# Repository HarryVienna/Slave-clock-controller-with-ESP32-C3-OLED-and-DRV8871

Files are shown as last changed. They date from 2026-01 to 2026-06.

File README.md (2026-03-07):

# ESP32-C3 Slave Clock Controller

A compact, affordable, and robust controller for analog slave clocks and flip clocks (e.g., Bodet), based on the **ESP32-C3** microcontroller and the **DRV8871** H-Bridge driver.




## 📖 Overview

This project replaces bulky and expensive master clocks with a tiny PCB powered by a single Li-Ion battery. It synchronizes time via NTP and offers a web-based configuration interface.

**Key Features:**
* **Universal Support:** Works with standard 12V/24V slave clocks and Bodet flip clocks (including date motor support).
* **Compact Design:** Built around the tiny ESP32-C3 (RISC-V) and DRV8871.
* **Battery Backup:** Integrated TP4056 charging logic with deep discharge protection; keeps time during power outages.
* **WiFi Provisioning:** Easy setup via a Captive Portal (no hardcoded credentials).
* **OLED Display:** Shows status, IP, and current time (0.42" OLED).
* **Automatic Catch-up:** Automatically fast-forwards the clock if it lags behind system time.

🔗 **Read the full story and build log:** [Harald Kreuzer's Blog](https://www.haraldkreuzer.net/en/news/slave-clock-controller-esp32-c3-and-drv8871-compact-and-affordable)

## 🛠 Hardware Components

The system is built using four main modules:

1.  **Microcontroller:** ESP32-C3 (RISC-V, Single Core) with 0.42" OLED.
2.  **Motor Driver:** DRV8871 H-Bridge (3.6A peak, 6.5V-45V).
3.  **Power Management:** TP4056 USB-C Li-Ion charger.
4.  **Voltage Booster:** SX1308 Step-Up Converter (boosts battery voltage to 12V/24V).

> **Note for Bodet Clocks:** The PCB includes slots for specific diodes to drop the voltage for the 3V date motor found in Bodet flip clocks.

## 🔌 PCB

PCB Image

## 💻 Software Architecture

The firmware is written in C++ using the **ESP-IDF Framework**. It is modular and uses FreeRTOS tasks.

```mermaid
graph TD
    Main[main.cpp] --> SlaveClock
    Main --> Display
    Main --> Button
    Main --> WifiProv[WifiProvisioner]
    
    SlaveClock -->|GPIO| DRV8871[Motor Driver]
    Display -->|I2C| OLED[SSD1306]
    Button -->|GPIO| UserInput
    WifiProv -->|WiFi| SNTP[NTP Server]
```

### Modules
* **SlaveClock:** Manages the Lavet stepper motor logic (polarity inversion) and tracks the hands' position.
* **Display:** Handles the UI via `u8g2` library, including a screensaver to prevent burn-in.
* **Button:** Debounces input and detects Short Press, Long Press, and Double Click.
* **WifiProvisioner:** Handles the Captive Portal and SNTP synchronization.

## 🤝 Acknowledgments

* **PCBWay** for sponsoring the PCB manufacturing for this project.
* **u8g2** library for the display graphics.

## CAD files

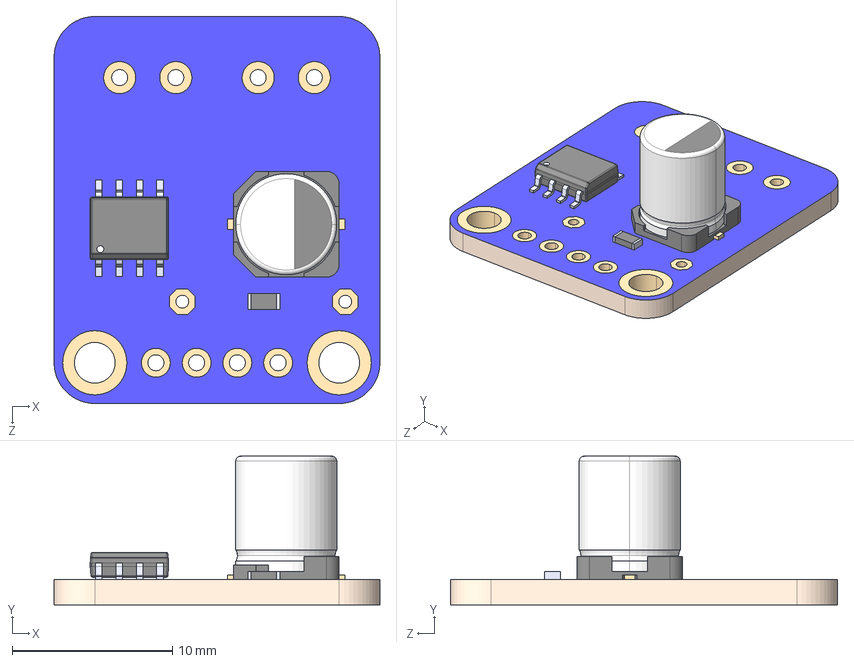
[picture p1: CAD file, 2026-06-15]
KiCAD/DRV8871/DRV8871.step
20.3 x 9.27 x 24.1 mm
Panasonic_D_22uF_63V_Panasonic_D_22uF_63V
DRV8871_DRV8871

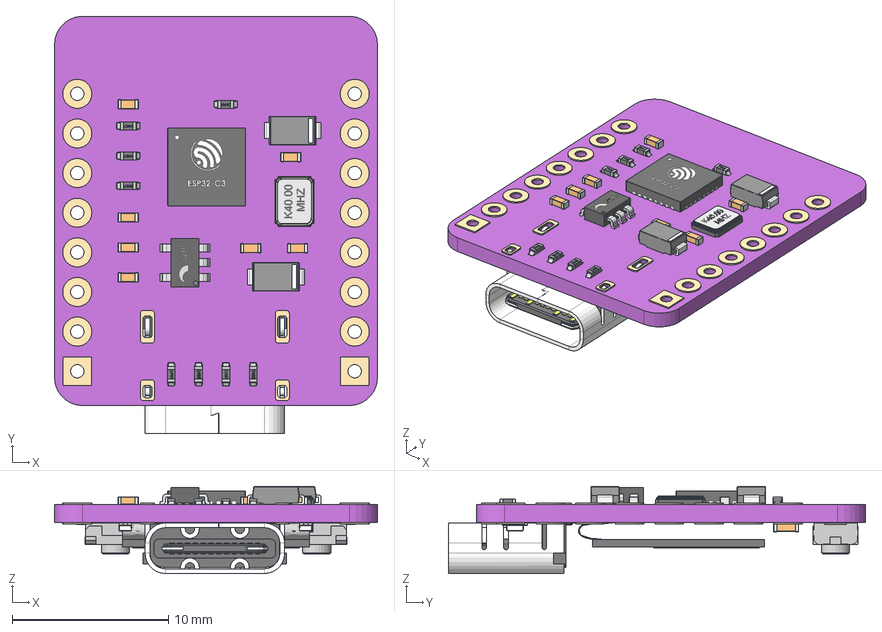
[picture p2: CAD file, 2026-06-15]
KiCAD/ESP32-C3_OLED/ESP32-C3_OLED4.2.step
20.7 x 26.7 x 5.58 mm
ESP32-C3
40.00 MHz Oscillator v1
Light x 2
Anode Bottom x 2
Cathode Bottom x 2
Anode x 2
Cathode x 2
Base x 2
3x4x2 tact button v1 v1 x 2
ME6211-SOT23 v1
USB_type_C_smd_12p v1
Anode Bottom (1)
Cathode Bottom (1)
Anode (1)
Cathode (1)
Base (1)
Text
Board
OLED 4.2
Pads
Resistor 0402 v1 x 8
Resistor 0402 v1 (1)
Refdes x 2
Cathode (2) x 2
Anode (2) x 2

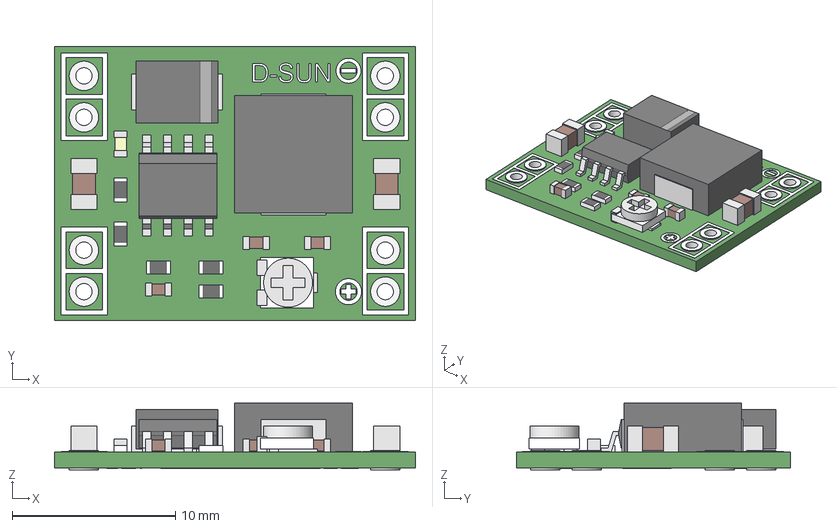
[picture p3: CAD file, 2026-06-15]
KiCAD/MP1584EN/MP1584EN_Module.step
22.1 x 16.8 x 4.10 mm
main001
silk-TOP
pins
silk-bot
comp-top

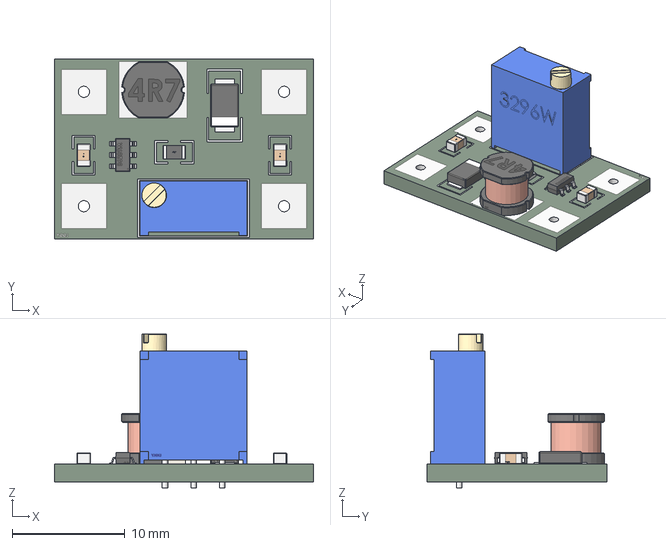
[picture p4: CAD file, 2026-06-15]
KiCAD/SX1308/YAAJ_DCDC_StepUp_SX1308_cp.step
23.0 x 16.0 x 13.7 mm

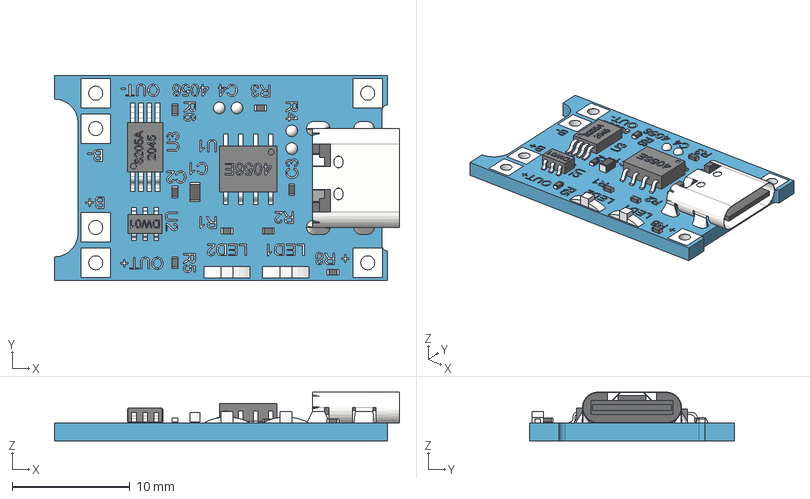
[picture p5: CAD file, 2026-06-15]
KiCAD/TP4056/TP4056_Charging_Module_Type_C.step
29.3 x 17.4 x 4.14 mm
board
USB_Type_C_Connector
8205A_2045
DW01-P
small1005_smd_resistor x 2
small1005_smd_resistor (1)
small1005_smd_capacitor
smd_capacitor
SOP-8_4056E
solder_dot_round
solder_dot_round (1)
solder_dot_round (2)
solder_dot_round (3)
small1005_smd_capacitor (1)
LED2
LED2 (1)
small1005_smd_resistor (2)
small1005_smd_resistor (4) x 2
soldering

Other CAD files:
KiCAD/DRV8871/DRV8871.stp

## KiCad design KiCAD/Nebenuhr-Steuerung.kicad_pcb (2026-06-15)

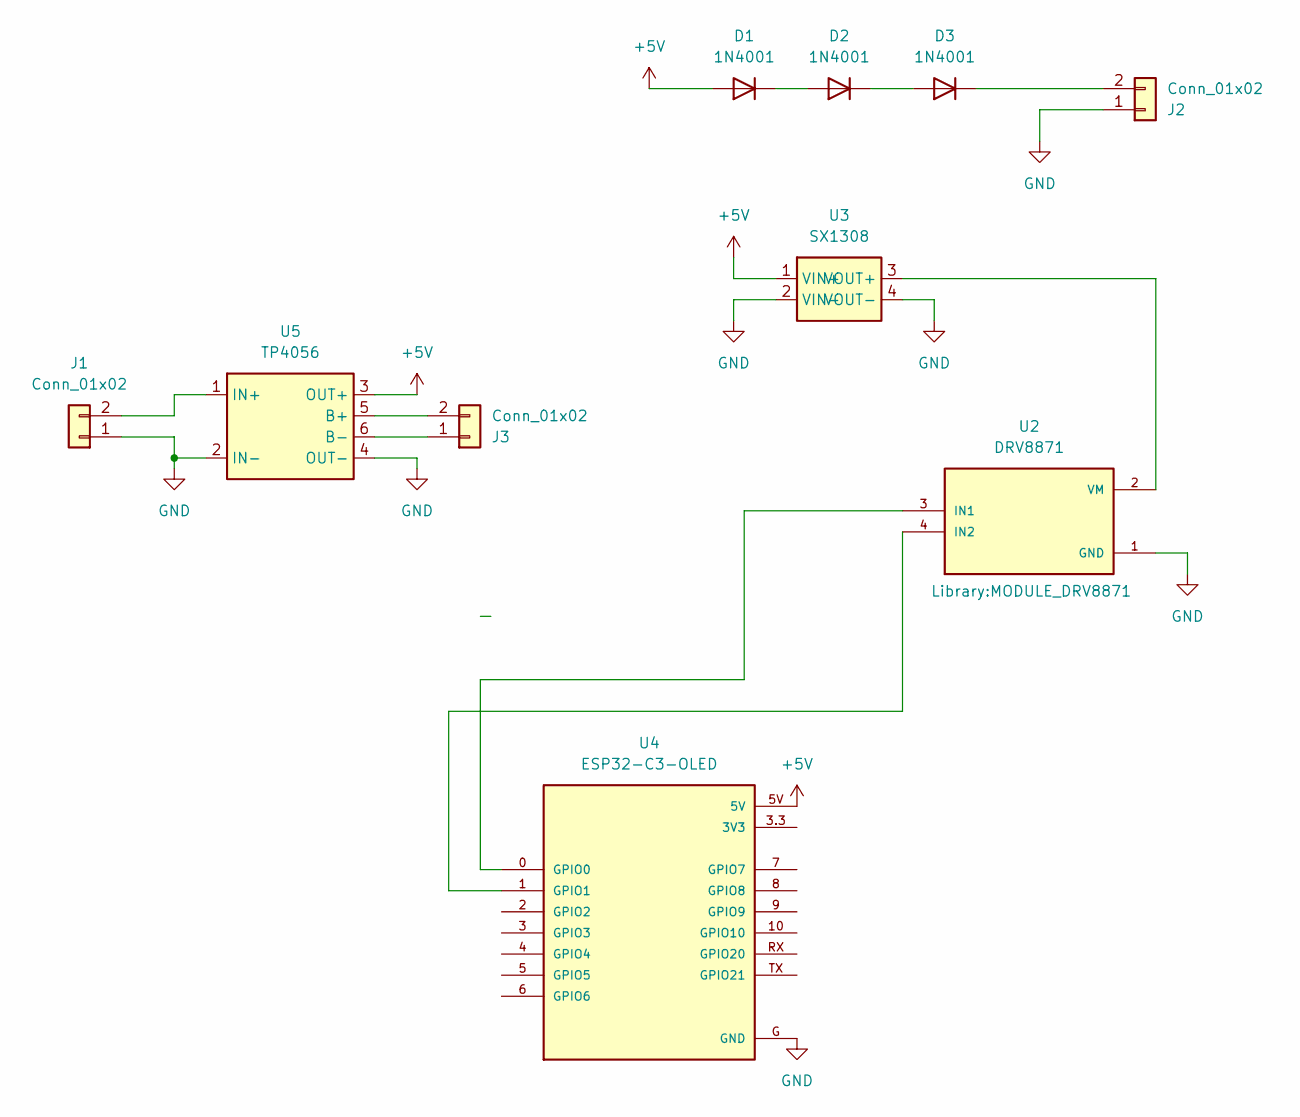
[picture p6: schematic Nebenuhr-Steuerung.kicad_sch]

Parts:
D1, D2, D3: 1N4001; D_DO-41_SOD81_P10.16mm_Horizontal
J1, J2, J3: Conn_01x02; TerminalBlock_Phoenix_PT-1,5-2-5.0-H_1x02_P5.00mm_Horizontal
U2: DRV8871; MODULE_DRV8871; PARTREV 2021-11-15
U3: SX1308; SX1308_Boost_Module
U4: ESP32-C3-OLED; MODULE_ESP32-C3_OLED
U5: TP4056; TP4056_Module_Protect

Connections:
+5V: D1.2 (A), U3.1 (VIN+), U4.5V, U5.3 (OUT+)
GND: J1.1, J2.1, U2.1 (GND), U3.2 (VIN-), U3.4 (VOUT-), U4.G (GND), U5.2 (IN-), U5.4 (OUT-)
unnamed: D1.1 (K), D2.2 (A)
unnamed: D2.1 (K), D3.2 (A)
unnamed: D3.1 (K), J2.2
unnamed: J1.2, U5.1 (IN+)
unnamed: J3.1, U5.6 (B-)
unnamed: J3.2, U5.5 (B+)
unnamed: U2.3 (IN1), U4.0 (GPIO0)
unnamed: U2.4 (IN2), U4.1 (GPIO1)
unnamed: U2.2 (VM), U3.3 (VOUT+)

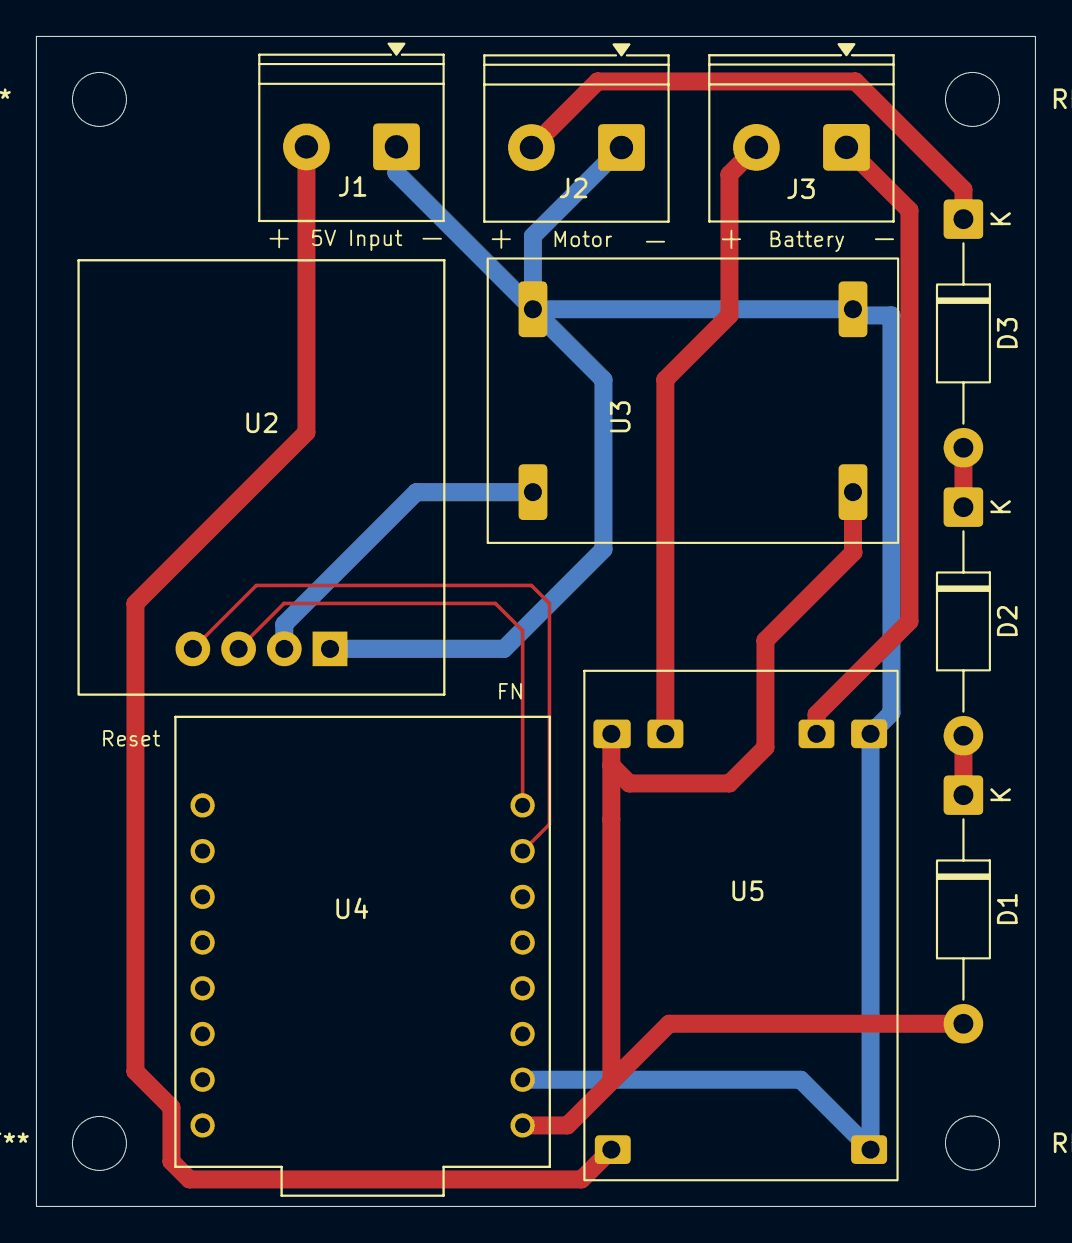
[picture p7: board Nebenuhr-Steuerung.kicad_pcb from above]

Board: 2 copper layers, 55.5 x 65.0 mm, 10 parts (0 on the bottom side), 11 nets.

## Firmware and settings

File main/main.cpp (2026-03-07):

#include <stdio.h>
#include <time.h>

#include "freertos/FreeRTOS.h"
#include "freertos/task.h"
#include "esp_log.h"

#include "display.hpp"
#include "slave_clock.hpp"
#include "wifi_provisioner.hpp"
#include "button.hpp"

#include "config.h"



static const char* TAG = "MAIN_APP";



extern "C" void app_main(void) {

    SlaveClock clock(PULSE_GPIO_HBRIDGE1, PULSE_GPIO_HBRIDGE2, PULSE_GPIO_LED,
                PULSE_WIDTH_MS, PULSE_INTERVAL_MS);

    Display oled;
    oled.init(PIN_SDA, PIN_SCL);
    oled.setScreensaverTimeout(5 * 60);  // Display nach 5 Minuten ausschalten

    // Button initialisieren (active_low, da gegen GND geschaltet)
    Button button(BUTTON_PIN);

    // Bei kurzem Tastendruck Display ein-/ausschalten
    button.onShortPress([&oled](Button::PressType) {
        oled.togglePower();
    });

    // Initialer Status (wird erst sichtbar wenn Display eingeschaltet wird)
    oled.disp_status("Booting...");
    vTaskDelay(pdMS_TO_TICKS(1000));



    WifiProvisioner provisioner;

    if (provisioner.is_provisioned()) {
        provisioner.get_credentials();
    } else {
        oled.disp_status("Provisioning...");
        provisioner.start_provisioning("ESP32-WiFi-Provisioning", false);
    }

    oled.disp_status("Connecting...");
    provisioner.connect_sta();

    oled.disp_status("Synching time");
    while(!provisioner.is_time_synchronized()) {

        ESP_LOGI(TAG, "Zeit ist noch nicht mit dem NTP-Server synchronisiert.");

        // Warte eine Sekunde bis zur nächsten Ausgabe
        vTaskDelay(pdMS_TO_TICKS(1000));
    }

    oled.disp_status("Time synched"); 
    clock.setTime(provisioner.get_provisioned_hour(), provisioner.get_provisioned_minute());
    vTaskDelay(pdMS_TO_TICKS(1000));

    // Hauptschleife
    while (true) {

        time_t now;
        time(&now);

        struct tm timeinfo;
        localtime_r(&now, &timeinfo);

        oled.disp_time(timeinfo);

        clock.update();

        vTaskDelay(pdMS_TO_TICKS(1000));
    }

}

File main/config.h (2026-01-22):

#pragma once

#include <sdkconfig.h>

#define PIN_SDA      GPIO_NUM_5
#define PIN_SCL      GPIO_NUM_6

#define PULSE_WIDTH_MS    350  // Pulse duration in milliseconds
#define PULSE_INTERVAL_MS 150  // Time between pulses
#define PULSE_GPIO_HBRIDGE1 GPIO_NUM_0 // Pin for Input1 of DRV8871 
#define PULSE_GPIO_HBRIDGE2 GPIO_NUM_1 // Pin for Input2 of DRV8871 
#define PULSE_GPIO_LED GPIO_NUM_8 // LED Pin of ESP32 C3 Board

#define BUTTON_PIN GPIO_NUM_9 // Button Pin

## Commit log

2026-01-22 Revise README for ESP32.C3 and DRV8871 driver
    Updated project description to reflect the use of ESP32.C3 and DRV8871 driver.
2026-02-03 Revise README for ESP32-C3 Slave Clock Controller
    This README update provides a comprehensive overview of the ESP32-C3 Slave Clock Controller project
2026-02-14 Revise PCB section in README
    Updated section headings and removed redundant text about circuit design.
2026-06-15 Add KiCAD files
    [DRV8871.step, DRV8871.stp, ESP32-C3_OLED4.2.step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]

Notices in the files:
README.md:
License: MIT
